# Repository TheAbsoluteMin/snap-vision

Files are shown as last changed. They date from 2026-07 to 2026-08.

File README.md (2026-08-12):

# SnapVision
Automated 3D scanner utilizing photogrammetry.



## See it in action
Demonstration [link](https://canva.link/5rpxtrnuvlr2msd).
<details>
<summary>
  <h3>Pictures</h3>
</summary>





</details>

## Inspiration
Designing cases or models for real world parts through CAD can be difficult without exact measurements and dimensions. Obtaining such measurements and replicating intricate designs on some objects and electronic modules can also be tedious. Thus, I decided to build an automated 3D scanner that uses photogrammetry. With custom firmware and access to Open Scan API, SnapVision seeks to make the 3D scanning process hands-free and streamlined after the initial run of the firmware. I hope this project can potentially expedite the engineering and design processes.

## Features
* High resolution camera
* Interactive display screen
* Portable, sleek case design
* Heat escape grills
* Internal LEDs
* Powerful yet stable motor
* Fully integrated and automated API processing
* Adaptive 3D model ZIP file download handling
* Real-time feedback during use

## Firmware Logic
1. Scanning
    1. Take a photo of the object
    2. Rotate object
    3. Repeat


2. Send images to API
    1. Verify API token
    2. Check photo data requirements
    3. Compress images in ZIP file(s)
    4. Send images


3. Extract the 3D model from API
    1. Check API processing status every 30 seconds
        1. If success:
            1. Check API dlink endpoint for download link
                1. If download link given, extract it
                2. If not, use IMAP to extract it from email
            2. Download ZIP file
            3. Find .obj 3D model file
            4. Show 3D model on display screen
        2. If failure:
            1. Try again



## Hardware
SnapVision uses some parts from the GoPiGo3 while integrating external components, including the Raspberry Pi 4, LED strip, and Hosyond 5 inch display screen. The following is a full wiring diagram.

17beecfb159768de8a5b11c459478a4fd769f798-2

Below shows where each jumper wire connects to.



## CAD Case
3D model [link](https://cad.onshape.com/documents/4bb380a378ec8b5d44400d73/w/f93c1e6eb205d04d3b317060/e/29820a57393d4c7f3e63d056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).

The case design evolved heavily from the first design.



Issues with space and hardware integration in the first design called for a remake. The second and final design was inspired by the Formlabs 3D printer design. 




## BOM
| Part Name | Quantity | Price | Where to Buy |
| :--- | :---: | :---: | :--- |
| GoPiGo3 | 1 | $199.00 | [GoPiGo](https://gopigo.io/gopigo/) |
| Raspberry Pi 4 | 1 | $40.34 | [Vilros](https://vilros.com/products/raspberry-pi-4-model-b-1?src=raspberrypi) |
| Female to Female Jumper Wires | 1 | $1.95 | [DigiKey](https://www.digikey.com/en/products/detail/adafruit-industries-llc/1950/6827084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) |
| Raspberry Pi Camera Model 3 Wide | 1 | $35.00 | [DigiKey](https://www.digikey.com/en/products/detail/raspberry-pi/SC1224/17278644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) |
| LEDs | 1 | $26.65 | [BTF-LIGHTING](https://www.btf-lighting.com/products/1-sk9822-led-pixel-strip-data-and-clock-dc5v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) |
| Hosyond 5 inch DSI Display Screen | 1 | $34.99 | [Amazon](https://www.amazon.com/Hosyond-Touchscreen-Compatible-Capacitive-Driver-Free/dp/B0CXTFN8K9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) |
| FFC Ribbon Cables | 2 | $3.99 | [Micro Center](https://www.microcenter.com/product/455642/1-Meter_Flex_Cable_for_Raspberry_Pi_Camera?storeID=061) |
| Total| | $345.91 | *Before Shipping* |

## How to use
1. Make sure SnapVision is in a well-lit place.
2. Place an object to be scanned on top of SnapVision's platter.
3. Run the main firmware at [scan.py](https://github.com/TheAbsoluteMin/snap-vision/blob/main/firmware/scan.py) (python) or [scan.ipynb](https://github.com/TheAbsoluteMin/snap-vision/blob/main/firmware/scan.ipynb) (Jupyter Lab) on the Raspberry Pi 4.
4. Fill in the firmware prompts by typing in the object's name and the number of photos to be taken.
5. Watch SnapVision take photos, and wait until SnapVision finishes processing them with the Open Scan API.
6. Wait for a success message and a 3D model preview of your completed scan!

## Full assembly
<details>
<summary>
  <h3>A. Set up hardware</h3>
</summary>

1. Connect the Pi Camera Model 3 to the Raspberry Pi 4 with an FFC ribbon cable with the cable clips. Make sure you connect to the Pi 4's "CAMERA" cable clip.



2. Connect the Hosyond DSI Display to the Raspberry Pi 4 with another FFC ribbon cable with the cable clips. Make sure you connect to the Pi 4's "DISPLAY" cable clip.



3. Attach the screws and standoffs on the Raspberry Pi 4.



4. Attach the Dexter GoPiGo3 red board on top of the Raspberry Pi 4.



5. Connect the DC motor with rotary magnetic encoder to the Dexter GoPiGo3 red board with the JST connector wires. Make sure you connect to the left JST connector port on the red board.



6. Attach the LED strip to the jumper wires (for extension) and wire them to the red board as shown below.





7. After following the Raspberry Pi 4 set up below, the battery pack can be connected to the red board's barrel jack. Remember, when powering on, always turn on the battery pack into the barrel jack before pressing the power button on the red board to start up the Pi 4. When turning off, press the power button on the red board before turning off the battery pack.


</details>

<details>
<summary>
  <h3>B. Install Pi OS</h3>
</summary>

1. Already have it
If you already have the OS installed, you can skip this guide!

2. Quick setup with SD card reader
Follow the official guide at https://www.raspberrypi.com/documentation/computers/getting-started.html.

3. Advanced setup without SD card reader
Use this method if you only have a USB drive (and optionally a microSD card).

    1. Download Pi OS (64 Bit)
        - Go to the [Raspberry Pi Software Page](https://www.raspberrypi.com/software/operating-systems/).
        - Download the 64-bit installer.
        - You should get a download with a name similar to "raspios-trixie-arm64.img.xz"
        

    2. Download Rufus
        - Go to [Rufus.ie](https://rufus.ie/en/).
        - Download the latest Windows version.
        

    3. Flash USB drive
        - Plug a clean USB drive into your windows computer.
        - Open Rufus.
        - Select your USB drive under Device.
        - Click SELECT and choose your downloaded Pi OS file.
        - Click START.
        - Wait for STATUS to show READY after flashing, which means it is done.
        

    4. Boot the Raspberry Pi 4
        - Important: If copying data to a microSD card later, do not insert the microSD card yet.
        - Plug the flashed USB drive into a blue USB 3.0 port.
        - (Optional) Connect the DSI display, mouse, and keyboard into the black USB 2.0 ports, which can help with setup.
        - Power on the Pi itself using a high-quality USB-C power cable and its USB-C port.
        - Follow the prompts to complete your preferences setup.

    5. (Optional) Copy OS to micro SD card
        - Insert your microSD card into the Pi 4's card slot.
        - Open the Raspberry Pi Imager application: Raspberry Pi Icon ➔ Accessories ➔ Raspberry Pi Imager.
        - Set Device to Raspberry Pi 4.
        - Set Operating System to Raspberry Pi OS (64-bit).
        - Click Storage and select your micro SD card.
        - Set your preferences.
        - (Recommended) Enable SSH to allow wireless coding.
        - Click Write
        - After writing, exit out of the Raspberry Pi Imager and enter the Pi terminal.
        - Type the command:
            > sudo poweroff
        - Unplug the USB flash drive and USB-C charger cable.
        - You can now plug in power from the battery pack into the GoPiGo3 red board's barrel jack.
</details>

<details>
<summary>
  <h3>C. Install firmware</h3>
</summary>

1. Install GoPiGo3

In the Pi terminal, type the commands:

> mkdir -p ~/.venv && python3 -m venv ~/.venv/robotics

> ~/.venv/robotics/bin/pip install mr-gopigo3

> source ~/.venv/robotics/lib/python3.*/site-packages/gopigo3/scripts/install_trixie.sh

2. (Optional) Install Jupyter Lab for coding

In the Pi terminal, type the commands:

> ~/.venv/robotics/bin/pip install jupyterlab

> ~/.venv/robotics/bin/jupyter lab --ip=0.0.0.0 --no-browser

The latter starts the web server broadcast. In order to open it up, you can type the access and token link displayed on the Pi terminal.

To have the server run in the background every time, create an automation file in the Pi terminal with the command:
> sudo nano /etc/systemd/system/jupyter.service

Then, type the following setup text inside: 

> [Unit]

> Description=Jupyter Lab Robot Server

> After=network.target

> [Service]

> Type=simple

> User=gopigo

> WorkingDirectory=/home/gopigo

> ExecStart=/home/gopigo/.venv/robotics/bin/jupyter lab --ip=0.0.0.0 --no-browser

> Restart=always

> RestartSec=10

> [Install]

> WantedBy=multi-user.target"

Make sure you replace "gopigo" as needed if you changed your Pi 4's username. Save and exit with Ctrl+O, Enter key, and Ctrl+X. Run the commands in the terminal to finish:
> sudo systemctl daemon-reload

> sudo systemctl enable --now jupyter.service

3. Install firmware libraries

Type the following commands in the Pi terminal:

> sudo apt update && sudo apt install f3d -y

> sudo apt update && sudo apt install -y python3-picamera2

> sudo apt update && sudo apt install -y swig

> sudo apt update && sudo apt install -y liblgpio-dev

> ~/.venv/robotics/bin/pip install jupyterlab mr-gopigo3 opencv-python adafruit-circuitpython-dotstar

Now, type in:

> nano ~/.venv/robotics/pyvenv.cfg

and change the word "false" in "include-system-site-packages = false"

to "true"

then hit Ctrl+O, Enter key, and Ctrl+X to save and exit.

4. Flash main firmware

If you are coding in Jupyter Lab, you can run the code directly on its web server. Otherwise, you can download scan.py onto your Pi 4 from [here](https://github.com/TheAbsoluteMin/snap-vision/blob/main/firmware/scan.py). With Jupyter Lab, you can convert your scan.ipynb file into scan.py with the Pi terminal command:
> ~/.venv/robotics/bin/python3 -m jupyter nbconvert --to script /home/pi4/Desktop/scan.ipynb

Doing so is suggested as you can run the code without a computer. In order to run the firmware by simply pressing on an icon, write the following command in the Pi terminal:
> nano ~/Desktop/Scan.desktop

Then, inside the text editor, write the following:
> [Desktop Entry]

> Name=Run Scan

> Comment=Runs robotics script

> Exec=/home/pi4/.venv/robotics/bin/python3 /home/pi4/Desktop/scan.py

> Icon=utilities-terminal

> Terminal=true

> Type=Application

and then press Ctrl + O, Enter key, and Ctrl + X to save and exit.

Finally, type the command in the terminal:
> chmod +x ~/Desktop/Scan.desktop

Before running the firmware, ensure you add your API token, which can be obtained by emailing the official Open Scan API email at cloud@openscan.eu. If you want to ensure SnapVision works all the time, please add your Gmail address and Gmail app password in case Open Scan API does not return a valid download link in its dlink endpoint.
</details>

<details>
<summary>
  <h3>D. Final Assembly</h3>
</summary>

You can reference the model assembly here: https://cad.onshape.com/documents/4bb380a378ec8b5d44400d73/w/f93c1e6eb205d04d3b317060/e/29820a57393d4c7f3e63d056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

Important: Please note that this guide assumes the color-coded parts, specifically the laser-cutted and 3D printed ones that were originally used.

Laser-cut parts can be found [here](https://github.com/TheAbsoluteMin/snap-vision/tree/main/CAD/Laser_Cutting). The parts with "Lid" or "Clear" in their name were cut in 3mm thick clear acrylic. The parts with "Internal" were cut in 3mm thick wood. All other laser-cut parts were cut in black acrylic.

3D printed parts can be found [here](https://github.com/TheAbsoluteMin/snap-vision/tree/main/CAD/3D_Printing).

However, you are able to 3D print everything.

1. Hot glue the following pieces together.




2. Assemble and hot glue the bottom case together.

3. Assemble and hot glue the top lid.

4. Assemble and hot glue the top case together. Make sure the 3D printed gray piece is in the back.

5. Hot glue the second floor parts together.

6. Hot glue the motor support in the 7th rectangular hole from the bottom in the bottom case's sides.

7. Place all the hardware inside the bottom case, and snap on the back bottom piece. That piece is the door to the power.

8. Attach the platter onto the DC motor.

9. Snap on the second floor parts together. Make sure the motor is taped or glued to the motor support.

10. Put together the camera using the Dexter camera mount.

11. Snap on the top case and top lid onto the second floor, and attach the Hosyond DSI display in the front.

</details>

## Credits
Thank you to the following:
- HackClub, for the opportunity and motivation to learn to build hardware projects!
- Tufts University Engineering Design Lab program, for access to instruction and fabrication materials!
- Ryan, for your support and contributions noted in the [JOURNAL.md](https://github.com/TheAbsoluteMin/snap-vision/blob/main/JOURNAL.md), specifically in the firmware and assembly of SnapVision!
- Thomas Megel from OpenScanCloud, for access to an API key and his example API code!

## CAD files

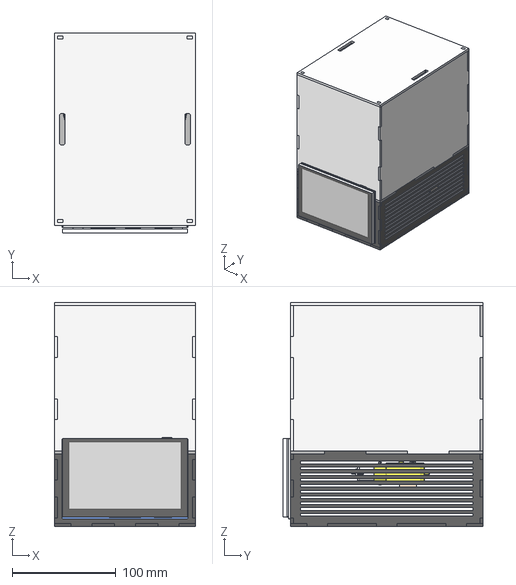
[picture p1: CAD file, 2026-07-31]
CAD/Full_Assembled_Model.step
136.0 x 193.3 x 216.0 mm

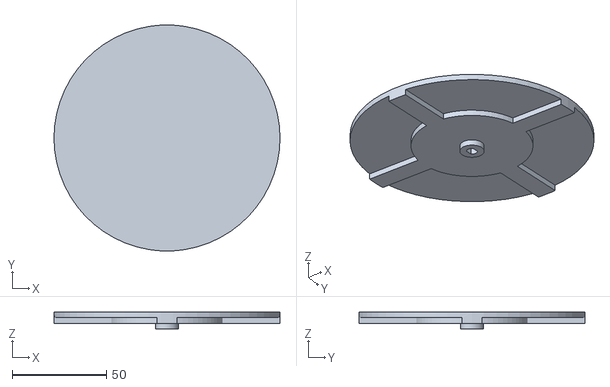
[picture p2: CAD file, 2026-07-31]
CAD/3D_Printing/PRINT_Platter.stl
120.0 x 119.8 x 9.00

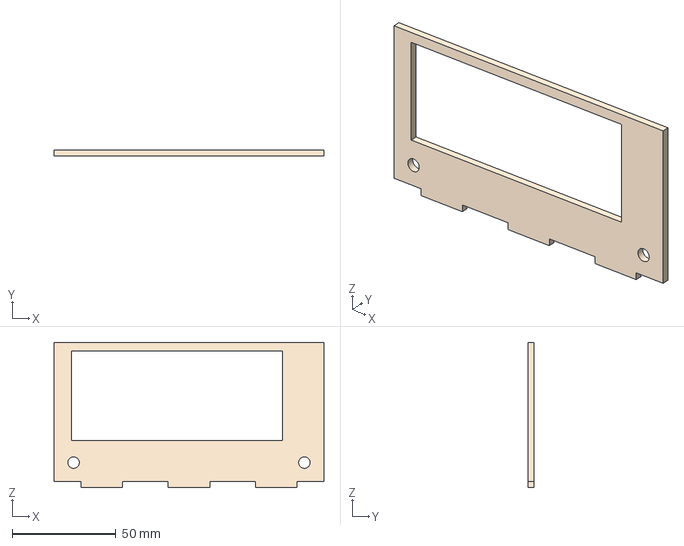
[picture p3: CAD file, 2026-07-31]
CAD/Front_Internal_Bottom_Wall.step
130.0 x 3.00 x 70.0 mm

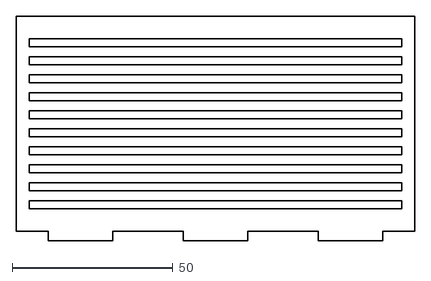
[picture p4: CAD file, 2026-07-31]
CAD/Laser_Cutting/Back_Internal_Bottom_Wall.dxf
124.0 x 70.0

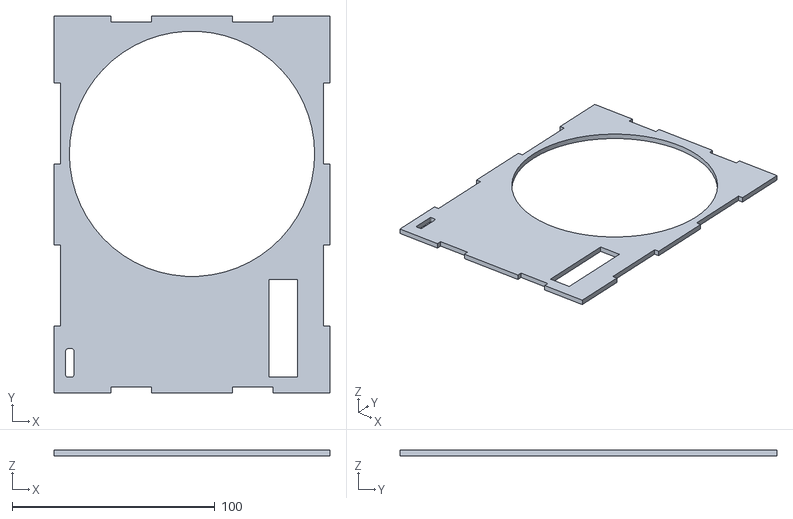
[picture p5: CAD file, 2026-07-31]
CAD/3D_Printing/PRINT_Second_Floor.stl
136.0 x 186.0 x 3.00

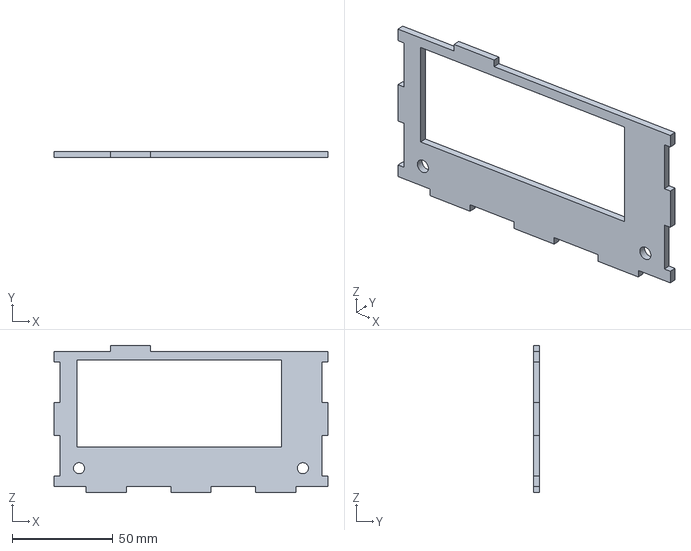
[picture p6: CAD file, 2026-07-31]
CAD/Front_External_Bottom_Wall.step
136.0 x 3.00 x 73.0 mm

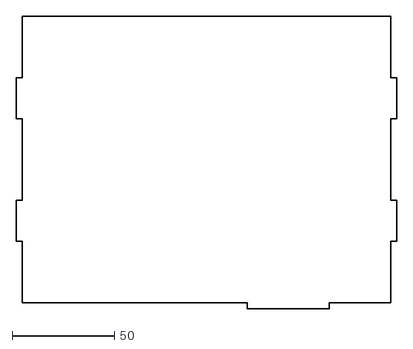
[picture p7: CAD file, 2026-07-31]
CAD/Laser_Cutting/Left_Top_Clear_Wall.dxf
186.0 x 143.0

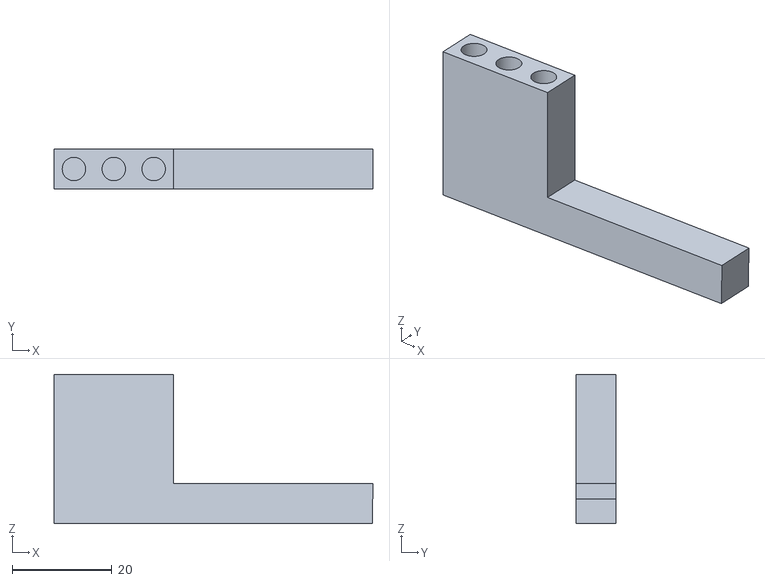
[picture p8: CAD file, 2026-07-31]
CAD/3D_Printing/PRINT_Camera_Base.stl
64.0 x 8.00 x 29.9

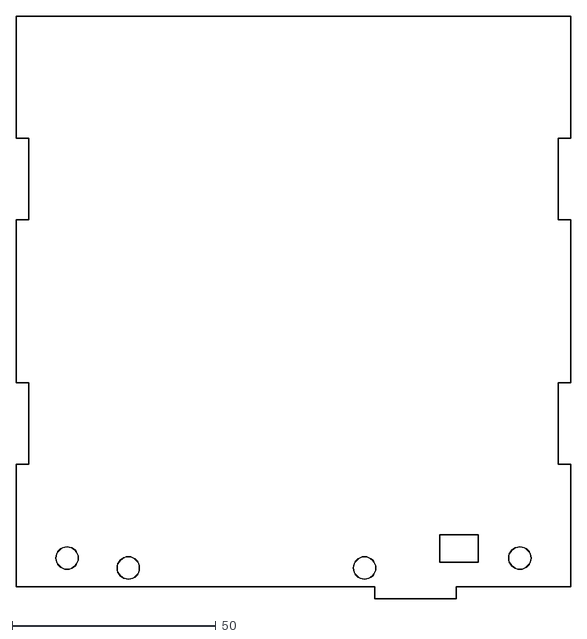
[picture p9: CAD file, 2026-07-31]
CAD/Laser_Cutting/Front_Top_Clear_Wall.dxf
136.0 x 143.0

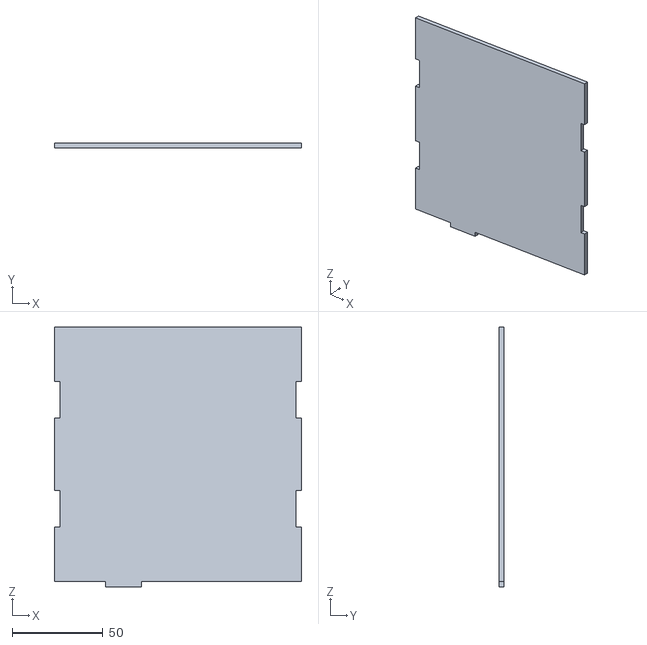
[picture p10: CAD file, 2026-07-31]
CAD/3D_Printing/PRINT_Back_Top_Wall.stl
136.0 x 3.00 x 143.0

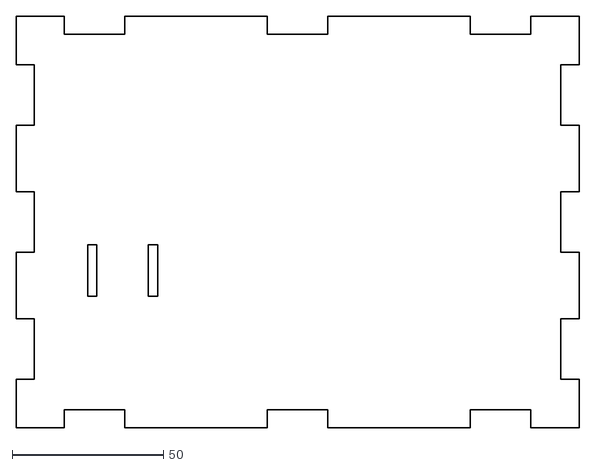
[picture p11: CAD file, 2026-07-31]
CAD/Laser_Cutting/Bottom_Case.dxf
186.0 x 136.0

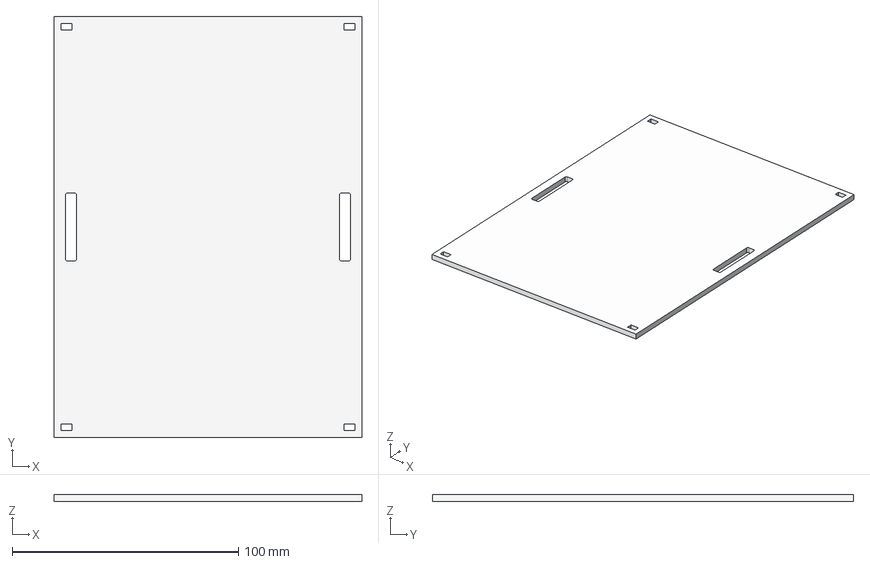
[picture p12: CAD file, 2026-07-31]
CAD/Top_Lid.step
136.0 x 186.0 x 3.00 mm

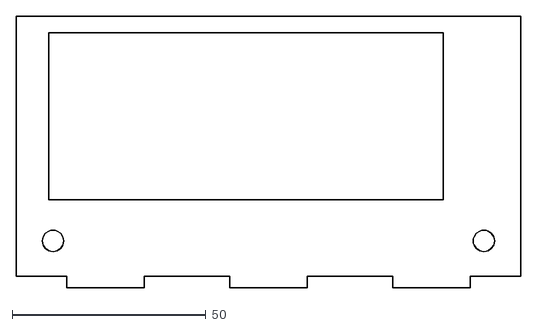
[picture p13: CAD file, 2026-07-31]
CAD/Laser_Cutting/Front_Internal_Bottom_Wall.dxf
130.0 x 70.0

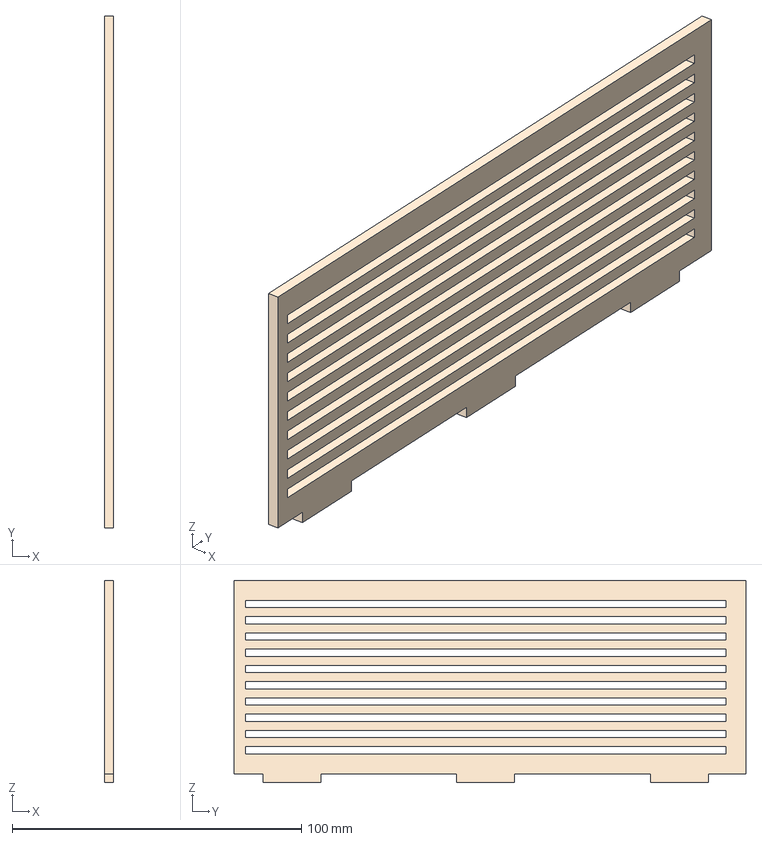
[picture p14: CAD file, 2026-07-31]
CAD/Left_Internal_Bottom_Wall.step
3.00 x 177.0 x 70.0 mm

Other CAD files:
CAD/Front_Left_Lid_Tab.step
CAD/Laser_Cutting/Back_Right_Lid_Tab.dxf
CAD/Front_Top_Clear_Wall.step
CAD/Laser_Cutting/Back_External_Bottom_Wall.dxf
CAD/Back_External_Bottom_Wall.step
CAD/Back_Internal_Bottom_Wall.step
CAD/Back_Left_Lid_Tab.step
CAD/Back_Right_Lid_Tab.step
CAD/Back_Top_Wall.step
CAD/Bottom_Case.step
CAD/Camera_Base.step
CAD/Front_Right_Lid_Tab.step
CAD/Laser_Cutting/Back_Left_Lid_Tab.dxf
CAD/Laser_Cutting/Front_External_Bottom_Wall.dxf
CAD/Laser_Cutting/Front_Left_Lid_Tab.dxf
CAD/Laser_Cutting/Front_Right_Lid_Tab.dxf
CAD/Laser_Cutting/Left_External_Bottom_Wall.dxf
CAD/Laser_Cutting/Left_Internal_Bottom_Wall.dxf
CAD/Laser_Cutting/Motor_Support.dxf
CAD/Laser_Cutting/Right_External_Bottom_Wall.dxf
CAD/Laser_Cutting/Right_Internal_Bottom_Wall.dxf
CAD/Laser_Cutting/Right_Top_Clear_Wall.dxf
CAD/Laser_Cutting/Top_Lid.dxf
CAD/Left_External_Bottom_Wall.step
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

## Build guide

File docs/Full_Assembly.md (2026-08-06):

# Full Assembly

View the 3D model here: https://cad.onshape.com/documents/4bb380a378ec8b5d44400d73/w/f93c1e6eb205d04d3b317060/e/29820a57393d4c7f3e63d056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

Important: Please note that this guide assumes the color-coded parts, specifially the laser-cutted (brown wood and clear and black acrylic) and 3D printed (gray) ones. However, you are able to 3D print everything. 

1. Hot glue the following pieces together.




2. Assemble and hot glue the bottom case together.

3. Assemble and hot glue the top lid.

4. Assemble and hot glue the top case together. Make sure the 3D printed gray piece is in the back.

5. Hot glue the second floor parts together.

6. Hot glue the motor support in the 7th rectangular hole from the bottom in the bottom case's sides.

7. Place all the hardware inside the bottom case.
???/n
8. Attach the platter onto the DC motor.


9. Snap on the second floor parts together. Make sure the motor is taped or glued to the motor support.

10. Put together the camera using the Dexter camera mount.
???
11. Snap on the top case and top lid onto the second floor.
???
12. Snap on the back bottom piece. This piece is the door to the power.
???
13. Snap on the Hosyond DSI display in the front.
???
14. Power on the battery, and press the power button on the red board to use. Enjoy!

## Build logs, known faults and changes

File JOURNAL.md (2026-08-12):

---
title: "SnapVision"
author: "TheAbsoluteMin"
description: "Automated 3D scanner utilizing photogrammetry."
created_at: "2026-07-26"
---

# Log 1: July 26, 2026 - Initial CAD Attempt - 3 hours
Timelapse <a href="https://lapse.hackclub.com/timelapse/oqR18RJn2kxE">link</a>.

Oftentimes, when I am designing a case for a project through CAD, I need to reference the dimensions and physical models of real world objects. However, obtaining measurements and replicating intricate designs on some objects and electronics can be difficult and time-consuming. Thus, I decided to build a 3D scanner that uses photogrammetry to automate the generation of 3D files for me, which can greatly expedite the engineering and design processes.

I began working on the CAD model for the 3D scanner, and I wanted to create a polygon shaped base.



However, I decided that the circular base was more elegant and simple to implement.



It was especially difficult to orient the camera in a natural place, but with some time, I was able to work around the camera so it would fit in.



Tomorrow, I will continue to plan and construct the 3D scanner case!

**Total time spent: 3 hours**

---

# Log 2: July 27, 2026 - CAD Part 2 - 1 hour
Timelapse <a href="https://lapse.hackclub.com/timelapse/i1yO9gOfZwh6">link</a>.

With the basic design finished, I worked on the internal components of the 3D scanner case, including holes and channels for wiring and electronics, especially the camera that is isolated far from the Raspberry Pi 4.



Underneath the case, I made room for the battery, Raspberry Pi 4, and DC motor with vents to dissipate the heat when the project runs.



This is what the model looks like as of now:



I will attempt to 3D print the pieces next time to evaluate them physically.

**Total time spent: 1 hour**

---

# Log 3: July 28-29, 2026 - CAD Part 2 - 5.6 hours
Timelapse <a href="https://lapse.hackclub.com/timelapse/_uOzVr4UmdGI">link</a>.

After finding a Hosyond 5 inch DSI display, I felt motivated to adapt my design to offer a more sleek appearance.



Initially, I wanted to use only a single backdrop wall for the camera, but the design did not look appealing.



However, with some research, I found great inspiration from the Formlabs 3D Printer.



And so, my work began. Since I had access to a laser cutter, I skipped the smooth fillets and bevels in order to use locking tabs, which would allow me to create the 3D scanner case much quicker. However, it was extremely time-consuming to create each tab! 




Integrating the DSI display was extremely hard, as the model CAD file for it took a lot of time for the system to process and handle, which greatly slowed down the workflow speed.



In order to provide a dynamic and robust 3D scanner, I decided to implement another motor to control the camera distance from the rotating platter that would hold the object. This would enable the 3D scanner to adjust for large and small objects.



Right now, this is what my project looks like:



The colors shown are not the final colors of the project as I needed to see a clear contrast for each part, but I am hoping to make the top part a white frosted acrylic material that is somewhat clear while the bottom case will be a simple black color.

Today, SnapVision welcomed a new collaborator and friend, Ryan. During the final project week of the Tufts Engineering Design Lab Pre-College Summer Program, he agreed to work with me on fabricating my 3D scanner! While I worked extensively on the CAD design today, Ryan worked on the foundation of the code for SnapVision, and he tested out the camera, motors, and LEDs. Despite some slight difficulties with camera colors, he was able to get the code to take clear pictures and rotate the DC motor by a few degrees and repeat while running white LEDs.

I have begun laser cutting some of the sides and 3D printing some of the mechanical parts. I hope to finish assembling the project tomorrow!

**Total time spent: 5.6 hours**

---

# Log 4: July 29-30, 2026 - Coding and Assembly - 3 hours
Assembly Timelapse <a href="https://lapse.hackclub.com/timelapse/1YW8Dd9PgHda">link</a>.
Coding hours tracked on Hackatime.

After Ryan calibrated and tested the code that rotated and captured pictures with the camera and motor, I worked on writing the code to send those pictures to the Open Scan API.

Here is what Ryan's code looked like:



He adjusted the code so that the firmware dynamically adjusted to users' choice of the number of pictures, which determined the angle step required to rotate the platter.



After calibrating the camera resolution and settings, he was able to allow the camera to capture quality pictures.



I had to learn how to use API code, and I quickly found it challenging.

I relied a lot on standard API code, and used a lot of place holder values as I did not have access to the Raspberry Pi 4 at that time.







When I finally was able to test and integrate the code with Ryan's, I found out quickly that it did not work... Then, I realized that I would have to read the Open Scan API GitHub and source code later!

After spending quite some time laser cutting and reprinting many parts due to inaccurate measurements and dimensions, my friend and I finally began on assembling the model! The box is mainly made up of laser-cut pieces, while pieces like the plane and walls that the camera views were 3D printed in gray to provide contrast when the API scans the pictures.



I had originally planned a sliding mechanism with a distance sensor that would move the camera with respect to the object on the platter, but after the coding tests, Ryan and I agreed that it was not necessary.

Also, I wanted the top clear case to be made out of frosted acrylic, but I later realized that Tufts program did not have any, so I used clear acrylic instead. 



The bottom base box has two layers for structural stability, with black matte acrylic material supported by birch wood. An interesting obstacle I faced when printing these layers included the high amount of time the laser cutter required to print tiny grills!





With a lot of hot glue, Ryan and I were able to put together a nice case with a sleek touchscreen display!






I hope to soon write a polished and fully complete firmware for my project as the Tufts program is ending on July 31, 2026, so Ryan will no longer be able to help me with the project and coding. However, I hope I can finished it!

**Total time spent: 3 hours**

---

# Log 5: August 4, 2026 - Raspberry Pi 4 Setup and Firmware - 6 hours
Timelapse <a href="https://lapse.hackclub.com/timelapse/Z6yoEgbLf6Xv">link</a>.

Wow, do I have a story to tell you! I was experimenting with the DSI display screen, and I wondered if I could display CAD files! Thus, I tried to run the lightweight F3D, a 3D viewer application, to display a simple .obj file.



However, I got the following error:



Apparently, my display screen did not have access, so I searched up a solution and found this code command:
> subprocess.run(["xhost", "+local:"])

However, it did not work still, so with further research, I came to the conclusion that it needed the Raspberry Pi 4 to run on X11 rather than the wayland session, so I tried to change that with some Pi terminal commands.

Long story short, it was not successful!

I tried to adjust the settings in the configuration tool, but the F3D viewer still did not run.



I tried to edit lightdm's session settings to default to X11, but that only gave me more errors! After rebooting the Pi 4, my display screen showed a really worrying page.



I was locked out of my virtual desktop! However, I was fortunate that the Jupyter Labs web server that the Tufts University program had installed still worked, so I opened a the Pi terminal from there! After reopening the lightdm settings, I realized that the Pi 4 had other settings that locked it in the Wayland session that I had missed and not changed. Thus, as the Pi 4 was in a conflicting state, I attempted to undo my work, but each terminal command and file edit seemed to make it worse, until I was not sure what I had done... I tried to reinstall the old packages for Wayland that I had accidentally deleted, and it did not work.



Files seemed missing and corrupted, and each command I typed may have actually made my situation worse rather than fix the problem. 



Thus, I finally decided to start anew and flash a brand new Pi OS. It was a difficult decision as that would mean the software and tutorials implemented by the Tufts University program would be erased, but I really wanted a working display screen! Flashing the new Pi OS was challenging as I did not have an SD card reader. With some reading, I found a way to flash the software onto a USB drive, which could be plugged into the Pi to start it. Then, I could use Raspberry Pi Imager to flash the cleaned micro SD card with the clean software! 

It took a few tries to flash the large software onto the USB drive since initially, the balenaEtcher software threw errors at the end after taking a long time to execute the flash!



Then, I switched to the Rufus software, and it finally worked!



The Pi 4 read the USB drive, and I was able to set up my preferences and flash the micro SD card with the clean Pi OS!

After all that painful work, I installed the GoPiGo3 and Jupyter Lab softwares again, so I could keep the same quick workflow where I could instantly test and run code. I ran into some errors with the GoPiGo3 software as it seemed to have needed other libraries like swig to help install and compile it.




After setting up the Jupyter Lab web server, I could finally begin coding. Of course, the code no longer natively worked in this new environment since I no longer had my program's software and libraries! Thus, I had to update the code so that it would work with standard libraries. The camera was especially difficult to reconfigure correctly so that it still took sharp images!



I began to adapt the Open Scan API's example code, and I hope to continue to integrate the API automation code into my project next time!

**Total time spent: 6 hours**

---

# Log 6: August 6-7, 2026 - More Coding - 3 hours
Timelapse <a href="https://lapse.hackclub.com/timelapse/wpJM3WVz891h">link</a>.

With the guidance of the example firmware in the Open Scan API GitHub, I integrated the firmware that would connect with the API server.



The API required a lot of verification steps, including token and photo data checks, before I could actually send the images over in the form of ZIP files.



I realized that the example firmware defaulted to returning an email with a ZIP Dropbox download! Since I wanted to make my 3D scanner automated, I needed to get the 3D model directly without manually opening up an email.

First, I tried to access my email through IMAP in order to retrieve the latest email.



Then, I could find the Dropbox download link in that email.



However, considering the safety and security implications of using an email credentials for this application, I wondered if there was a better way. Fortunately, after reading again through the API's GitHub README, I found an interesting word in the response fields of the Get Project Info endpoint.



With this, I tested to see if I could simply retrieve "dlink" in the firmware after the 3D model was created.



After downloading the Dropbox ZIP file with the firmware, I could extract it to access the .obj 3D model file! As a bonus, I decided to use F3D viewer to display the 3D model at the end!



Next time, I will test out the code again to make sure it works, so I can begin finishing up the GitHub repository!

**Total time spent: 3 hours**

---

# Log 7: August 9, 2026 - GitHub Work and Code Testing - 3 hours

Today, I extensively worked on putting together the GitHub repository files. Getting all the pictures and files together took quite some time, as I had to disassemble my project and then put it back together step by step in order to include assembly instructions!




Then, I spent an incredibly long amount of time just trying to get one full successful run of the firmware. However, the Open Scan API did not seem to work. There were data transmission errors despite no change of the working code from yesterday!



My first attempt in fixing this problem included reverting the file naming to the original one set by Open Scan. However, that did not work.

After comparing my API code with the example code from Open Scan API, I figured that there must have been a problem with the images that were being put into a ZIP file. Apparently, the Open Scan API code explicitly checked for allowed photo types like .jpg in order to prevent hidden files in the camera folder to be included in the ZIP file that would be sent over to the API server. I implemented that and the data transmission errors went away! 



However, a key problem with the API is that it does not always return dlink in its project information endpoint. Thus, I may have to revisit the email IMAP code.

I hope I can finally obtain a working video of SnapVision working!

**Total time spent: 3 hours**

---

# Log 8: August 10, 2026 - Firmware Fixes - 1.1 hours
Timelapse <a href="https://lapse.hackclub.com/timelapse/sTsILPRuamga">link</a>.

Today was a big day! After a long, hard fought war against my firmware, I finally was able to achieve a complete and successful run of the firmware! However, there were some notable problems with the code that I had to solve.

First, my previous code logic form downloading the ZIP file from the API returned an "is a directory error".



Thus, I had to use "os.path.basename(dlink)" in order to extract the end of the URL path, so that the firmware could download to a working folder path.



After some testing, I confirmed Open Scan API's interesting quirk where it would sometimes not include a downloadable link in its dlink API endpoint. To handle this, I implemented an adaptive handling feature where the code would first check the dlink endpoint before using an alternative method to get the ZIP download link. This is where the IMAP code, which I had initially rejected, now shines.

Now, instead of blindly targeting the latest email, the firmware targets the latest email from Open Scan API and finds the dlink in the email text, so I can download the ZIP file later.



A run of the firmware proved that my code finally worked, even when Open Scan API did not include the download link!



With some final edits to my GitHub repository, SnapVision is finally finished!

**Total time spent: 1.1 hour**

---

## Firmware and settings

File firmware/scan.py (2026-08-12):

from easygopigo3 import EasyGoPiGo3
from IPython.display import Image, display
from picamera2 import Picamera2
from picamera2 import libcamera
import cv2
import adafruit_dotstar as dotstar
import board
import time
import os
import requests
import zipfile
import urllib.parse
import subprocess
import shutil
import imaplib
import re
import email

### 0. Set up

#hardware
camera = Picamera2()
easyGPG = EasyGoPiGo3()
easyGPG.reset_encoders()
clock_pin = board.D6
data_pin = board.D5
num_leds = 120
brightness = 0.05
lights = dotstar.DotStar(clock_pin, data_pin, num_leds, brightness=brightness, auto_write=False)

##### Edit these! #####
token = "#####" #ask for a token at the official Open Scan API email: cloud@openscan.eu
IMAP = "imap.gmail.com" #fill out the below, optional but needed for 100% success to get downloadable link for 3D model
email_user = "#####" #your Gmail address
email_pass = "#####" #your Gmail app password

#API variables
folder = "/home/pi4/Camera/"
dir_temp = "/home/pi4/temp/"
zip_scanned = "/home/pi4/Scanned/"
zip_extracted = "/home/pi4/Extracted/"
server = "http://openscanfeedback.dnsuser.de:1334/"
user = "openscan"
pw = "free"
size_to_split = 200000000 #200MB max files size
msg = {"token": token}
allowed_extensions = ['.jpg', '.jpeg', '.png', '.JPG', '.JPEG', '.PNG']

#get API requests
def OpenScanCloud(cmd, msg_req):
    return requests.get(server + cmd, auth=(user,pw), params=msg_req)

#clean all folders
folders_clean = ["/home/pi4/Camera/", "/home/pi4/temp/", "/home/pi4/Scanned/", "/home/pi4/Extracted/",]
for folder in folders_clean:
    if os.path.exists(folder):
        shutil.rmtree(folder)
    os.makedirs(folder, exist_ok=True)

### 1. Scanning
#object preferences
object_name = input("Object Name: ")
num_photos = int(input("Number of Photos (20+ recommended): "))

#adaptive wheel speed
easyGPG.set_speed(10 * num_photos)
print(f"Speed: {10 * num_photos}.")

#LEDs on
lights.fill((255, 255, 255))
lights.show()
print("Lights on.")

#camera on max res: 4608 × 2592 pixels
cam_config = camera.create_still_configuration(main={"size": (4608, 2592)})
camera.configure(cam_config)
camera.set_controls(
    {
        "AwbMode": libcamera.controls.AwbModeEnum.Daylight,
        "AfMode": libcamera.controls.AfModeEnum.Manual, 
        "LensPosition": 12.0
    }
)
camera.start()
time.sleep(2)

cycle = 0
for _ in range(num_photos):
    cycle = cycle + 1
    file_name = os.path.join(folder, f"{object_name}_{cycle}.jpg")

    #take photo, save, and display
    frame = camera.capture_array()
    cv2.imwrite(file_name, cv2.cvtColor(frame, cv2.COLOR_RGB2BGR))
    display(Image(filename=file_name))
    time.sleep(0.5)

    #rotate platter
    easyGPG.turn_degrees(round(420/num_photos), blocking=False) #420 to account for motor imprecision
    time.sleep(1.5)

#LEDs and camera off
lights.fill((0, 0, 0))
lights.show()
camera.stop()
camera=None
print("Scan finished.")

### 2. Send to API

#verify token
token_info = OpenScanCloud("getTokenInfo", msg)

if token_info.status_code != 200:
    raise Exception(f"ERROR: token not verified {token_info.status_code}")

credit = token_info.json()["credit"]
print(f"Token verified. Credits left: {credit}.")

#check photo data
limit_file_size = token_info.json()["limit_filesize"]
limit_photos = token_info.json()["limit_photos"]

images = []
for image in os.listdir(folder):
    if os.path.splitext(image)[1] in allowed_extensions:
        images.append(image)

if len(images) == 0:
    raise Exception("ERROR: No images found")

file_size = 0
for image in images:
    file_size = file_size + os.path.getsize(os.path.join(folder, image))

msg["photos"] = len(images)

if file_size > limit_file_size or len(images) > limit_photos:
    raise Exception(f"ERROR: Photos too large! Max file size: {limit_file_size}. Max number of photos: {limit_photos}.")

print("Preparing images.")

#clean dir_temp folder
for i in os.listdir(dir_temp):
    try: os.remove(os.path.join(dir_temp, i))
    except: pass

project_name = str(int(time.time()*100))+ '-OSC.zip'
file = os.path.join(dir_temp, project_name)
msg["project"] = project_name

#zip images
with zipfile.ZipFile(file, "w") as zipf:
    for image in images:
        zipf.write(os.path.join(folder, image), image)

msg["filesize"] = os.path.getsize(file)
msg["partslist"] = [file]

#split up zip file if too large
if os.path.getsize(file) > size_to_split:
    msg["partslist"] = []
    number = 1
    with open(file, "rb") as f:
        chunk = f.read(size_to_split)
        while chunk:
            chunk_name = f"{file}_{number}"
            with open(chunk_name, "wb+") as chunk_file:
                chunk_file.write(chunk)
            msg["partslist"].append(chunk_name)
            number += 1
            chunk = f.read(size_to_split)
    os.remove(file)

msg["parts"] = len(msg["partslist"])

print("Sending images.")
r = OpenScanCloud("createProject", msg)
if r.status_code != 200:
    raise Exception("ERROR: Unable to create project")
ulinks = r.json()["ulink"]

#send zip file (parts)
for i, chunk_file_path in enumerate(msg["partslist"]):
    print(f"Uploading {i+1} of {len(msg["partslist"])} file(s).")
    with open(chunk_file_path, "rb") as f:
        data = f.read()
    r = requests.post(url=ulinks[i], data=data, headers={"Content-type": "application/octet-stream"})
    if r.status_code != 200:
        raise Exception("ERROR: Unable to send files")

print("Creating 3D model.")
r = OpenScanCloud("startProject", msg)
if r.status_code != 200:
    raise Exception("ERROR: Unable to start 3D model creation")

### 3. Extract download link from API and show 3D model on display

#check for 3D model download link
status_msg = {"token": token, "project": msg["project"]}

while True:
    time.sleep(30)
    r = OpenScanCloud("getProjectInfo", status_msg)
    if r.status_code != 200:
        print("ERROR: Unable to get scan info.")
        continue

    info = r.json()
    print("Scan info:", info)
    scan_status = info.get("status", "unknown")
    print(f"[{time.strftime("%X")}] Status: {scan_status}.")

    if scan_status == "processing done":
        time.sleep(10)
        dlink = info.get("dlink") #if Open Scan API returns dlink
        
        if not dlink: #if Open Scan API does not return dlink, use IMAP
            print("ERROR: No download link found. Using IMAP to find link.")
            time.sleep(20) #wait for email to send

            mail = imaplib.IMAP4_SSL(IMAP)
            mail.login(email_user, email_pass)
            mail.select("INBOX")

            #find latest email from Open Scan API
            status, messages = mail.search(None, '(FROM "cloud@openscan.eu")')
            if status == "OK" and messages[0]:
                newest = messages[0].split()[-1]
                _, data_message = mail.fetch(newest, "(RFC822)")
                target_message = email.message_from_bytes(data_message[0][1])

                text_message = ""
                for part in target_message.walk():
                    if part.get_content_type() in ["text/plain", "text/html"]:
                        text = part.get_payload(decode=True).decode(errors="ignore")
                        break
                        
                #get dlink from email
                links = re.findall(r'https?://[^\s"<]*openscan\.eu[^\s"<]*', text)
                if links:
                    dlink = links[0].replace("&amp;", "&")
                mail.logout()

        #extract dropbox zip download link
        parsed = urllib.parse.urlparse(dlink)
        qs = urllib.parse.parse_qs(parsed.query)

        dlink = qs["id"][0]

        if "dl=" not in dlink:
            dlink += "&dl=1"
        else:
            dlink = dlink.replace("dl=0", "dl=1")

        #download zip file from dropbox
        r = requests.get(dlink, allow_redirects=True)
        file_download = os.path.join(zip_scanned, os.path.basename(dlink))
        with open(file_download, "wb") as f:
            f.write(r.content)
        
        #extract zip file
        with zipfile.ZipFile(file_download, "r") as zip_r:
            zip_r.extractall(zip_extracted)
        print("ZIP Extraction complete!")

        #find .obj 3D model in extracted folder
        model = next((f for f in os.listdir(zip_extracted) if f.lower().endswith(".obj")), None)
        if not model:
            print("ERROR: No .obj 3D model found.")
            break
        else:
            path_model = os.path.join(zip_extracted, model)

            #display 3D model on F3D viewer
            ENV = os.environ.copy()
            ENV["WAYLAND_DISPLAY"] = "wayland-0"
            ENV["DISPLAY"] = ":0"
            ENV["XAUTHORITY"] = "/home/pi4/.Xauthority"
            subprocess.run(["f3d", "--resolution=760,400", "--position=20,70", path_model], env=ENV)
            print("Displaying 3D model!")
            break

    elif scan_status == "Processing failed":
        print("ERROR: Unable to create 3D model. Please try again.")
        break

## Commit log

2026-07-31 Add CAD STEP files
    [Back_External_Bottom_Wall.step, Back_Internal_Bottom_Wall.step, Back_Left_Lid_Tab.step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]
2026-07-31 Add full model STEP file
    [Full_Assembled_Model.step]
2026-07-31 Add 3D printing STL files
    [PRINT_Camera_Base.stl, PRINT_Platter.stl, PRINT_Second_Floor.stl]
2026-07-31 Add Back Top Wall STL file
    [Back_Top_Wall.stl]
2026-07-31 Rename file
    [PRINT_Back_Top_Wall.stl]
2026-07-31 Add updated STL files
    [PRINT_Camera_Base.stl, PRINT_Platter.stl, PRINT_Second_Floor.stl]
2026-07-31 Add fixed STEP files
    [Front_External_Bottom_Wall.step, Front_Internal_Bottom_Wall.step]
2026-07-31 Add laser cutting DXF files
    [Back_External_Bottom_Wall.dxf, Back_Internal_Bottom_Wall.dxf, Back_Left_Lid_Tab.dxf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]
2026-08-05 Update Raspberry_Pi_OS_Setup.md 1
2026-08-05 Update Raspberry_Pi_OS_Setup.md 2
2026-08-12 Add BOM file
    [BOM.csv]
2026-08-12 Add updated BOM file
    [BOM.csv]
